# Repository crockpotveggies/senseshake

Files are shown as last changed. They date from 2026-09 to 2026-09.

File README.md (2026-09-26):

Groundlark — lark and seismic waveform

# Groundlark — an open source seismic acquisition platform with support for FPGAs and BISCUT AI chips

Groundlark is an open hardware seismic acquisition platform combining a
Raspberry Pi, a three-IMU DAQHAT-01 sensor HAT, a Trenz Artix-7 200T FPGA module,
and a passive geophone.

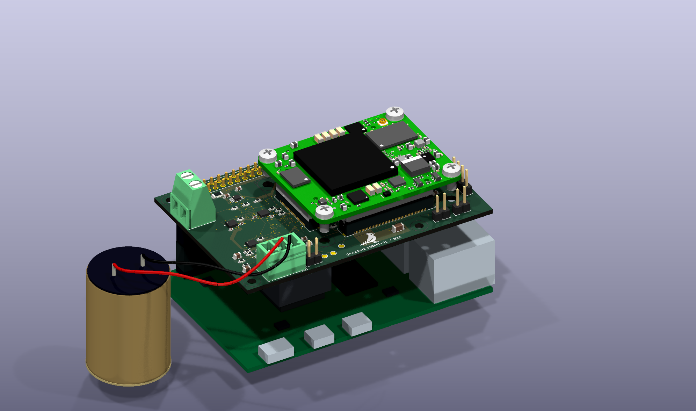
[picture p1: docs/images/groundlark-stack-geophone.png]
Groundlark: Raspberry Pi, DAQHAT-01 and Trenz FPGA stack with Racotech geophone


The image uses current HAT CAD and the vendor Trenz model. The Pi, baseline
socket and geophone are conceptual geometry; lead routing is illustrative.
The J1 procurement substitute needs a physical stack-height check.

## Hardware

The [DAQHAT-01](docs/trenz-hat.md) is an 85 × 56 mm, six-layer FR-4 carrier with
three XYZ LSM6DSO IMUs and one ADS122C04 input for an external Racotech geophone.
The stack is **Pi → HAT → Trenz FPGA**. It requires a separate regulated
3.3 V-class FPGA supply; follow the guide's voltage and power limits.

The [internal FPGA link](docs/fpga-host-link.md) reserves six QSPI wires and
supports UART, reset and switched Pi-driven JTAG without external ribbon cables.
Pi 4 initially uses SPI6; native quad transfers require a different host solution.
An SPI echo bitstream is implemented; accelerated sensor processing remains future work.

The [USB-C sensor head](docs/usb-sensor-head.md) carries an RM3100 magnetometer
and optional DLVR infrasound sensor. It connects to the Pi for power and data;
its MCU firmware is still pending. These sensors are separate from the HAT.
The [A2 ASIC HAT](docs/design-a0.md) and [Coldfoot integration](docs/coldfoot-integration.md)
are retained as a separate design; current hardware work focuses on the FPGA stack.

Use the [stack assembly guide](docs/stack-assembly.md) and
[JLCPCB instructions](docs/jlcpcb-assembly.md) for mechanical and manufacturing details.
The JLCPCB package targets **one assembled HAT**. Upload the corrected BOM and
CPL together. Supplier quantity, sourcing, placement and J1 fit checks remain open.
Fabrication packages stay local under ignored `hw/releases/`.

Physical power, fit, timing, noise and thermal qualification remain pending.
The [bench procedure](docs/bench-procedure.md) describes the required measurements.

## Sensor workbench

The dark-mode Python UI includes a selectable 3D HAT and geophone, six virtual
sensor streams, raw-data charts, stimulus/fault controls and recording/replay.
No hardware or Docker is required. Follow the
[beginner walkthrough](docs/sensor-workbench.md) to create your first signal.

```powershell
# Windows: set up once, then launch
./setup-ui.ps1 -Check
./ui.ps1
```

On Linux/macOS, use `sh ./setup-ui.sh --check`, then `sh ./ui.sh`.
Open **http://127.0.0.1:8080**. Tools and dependencies stay in ignored `.local/`.

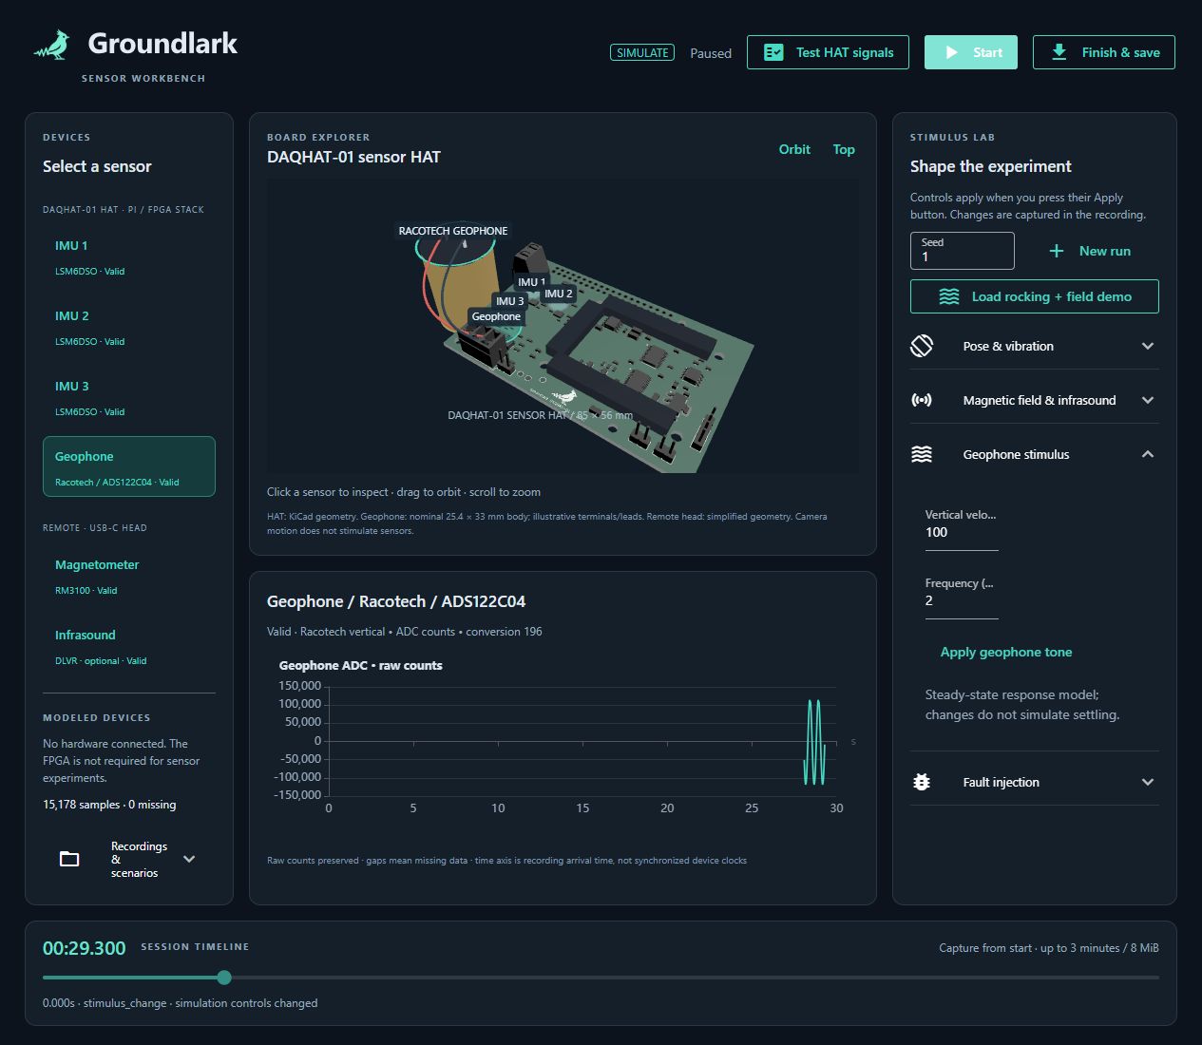
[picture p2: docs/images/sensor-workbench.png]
Groundlark sensor workbench showing the external geophone and a simulated 2 Hz signal


This is an actual browser screenshot with simulated data. Select the geophone
can or its HAT input to highlight both and inspect the same ADC stream.
**Test HAT signals** runs eight simulated seconds through production Pi drivers
on modeled buses, with signal checks and downloadable recordings/results.
The UI simulates and replays; physical acquisition uses the [Pi software](docs/sensor-software.md).

## Project files and tests

| Directory | Contents |
| --- | --- |
| [hw/](hw/README.md) | Atopile circuits, KiCad boards, models, hardware checks and SPICE. |
| [sw/](sw/README.md) | Pi acquisition, contracts, simulator, FPGA and remote firmware interfaces. |
| [docs/](docs/README.md) | Setup, hardware specifications, assembly, interfaces and testing instructions. |
| [environment/](docs/portable-lab.md) | Pinned Docker test environment and bounded cleanup tooling. |

For the full test environment, run `./lab.ps1 build` once, then `./lab.ps1 test`.
Use `./lab.ps1 test -Profile software` for sensor contracts, acquisition,
recording/replay and recovery. See the [portable lab guide](docs/portable-lab.md)
for Linux commands, test scope, five-run retention and cleanup.

Hardware sources: [DAQHAT-01 circuit](hw/elec/hat_trenz.ato),
[KiCad PCB](hw/boards/groundlark-daqhat-01/groundlark-daqhat-01.kicad_pcb),
[A2 HAT](hw/boards/groundlark-hat/groundlark-hat.kicad_pcb), and
[USB head](hw/boards/groundlark-field-head/groundlark-field-head.kicad_pcb).
See [build instructions](docs/build.md) and [source references](docs/sources.md).

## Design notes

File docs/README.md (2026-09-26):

# Documentation

## Getting started

- [Sensor workbench](sensor-workbench.md): installation, first experiment, recordings and replay.
- [Sensor software](sensor-software.md): command-line simulation and Pi acquisition.
- [Stimulus scenarios](stimulus-models.md): saved inputs, waveforms and sensor-model limits.
- [Project layout](project-layout.md): where to find hardware, software and generated files.

## Hardware and assembly

- [DAQHAT-01 hardware](trenz-hat.md): sensors, Trenz module, power, connectors and fabrication stack.
- [Pi/FPGA host link](fpga-host-link.md): SPI/QSPI pins, UART, JTAG and bring-up.
- [Geophone input](geophone-input.md): Racotech connection, analog circuit and accelerometer axes.
- [Stack assembly](stack-assembly.md): Pi, HAT, FPGA, cooling, supports and geophone lead.
- [JLCPCB assembly](jlcpcb-assembly.md): upload files, selected parts, placement and manufacturing requirements.
- [Physical bench procedure](bench-procedure.md): power, fit, timing and noise measurements.
- [A2 ASIC HAT](design-a0.md), [Coldfoot module](coldfoot-integration.md) and [A2 validation limits](validation.md).
- [USB sensor head](usb-sensor-head.md): magnetometer, optional infrasound and firmware interface.

## Interfaces and reproducible builds

- [Sensor data contract](sensor-contract.md) and [schema tools](../sw/interfaces/README.md).
- [GNSS timing](utc-timing.md): legacy hardware/recording support; GNSS is absent from DAQHAT-01.
- [Hardware build](build.md), [portable tests](portable-lab.md) and [SPICE scope](../hw/simulation/README.md).
- [Component and vendor references](sources.md).

The hardware is an engineering prototype. Modeled tests do not replace physical
power, fit, timing, thermal or noise qualification.

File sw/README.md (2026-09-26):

# Software

The sensor HAT is driven by Pi software; it does not need separate MCU firmware.
The [acquisition software](../docs/sensor-software.md) supports sensors on the
DAQHAT-01 FPGA stack and runs without Coldfoot or a configured FPGA.
The sensor contracts and Pi acquisition application are executable:

- [interfaces/](interfaces/README.md): Protobuf schemas, semantic validation and bounded USB framing.
- [pi/](pi/README.md): Pi device configuration, sensor drivers/adapters, acquisition,
  calibration and timestamps. Coldfoot host integration is deferred.
- [field-head/](field-head/README.md): microcontroller firmware for the remote
  USB-C magnetometer/infrasound board.
- [fpga/](fpga/README.md): Trenz pin/connectivity qualification and minimal test
  bitstreams; accelerator implementation is deferred.
- [tests/](tests/README.md): portable replay, fault injection and host integration.
- [ui/](ui/README.md): Python/NiceGUI local sensor workbench, board explorer,
  stimulus controls and recording/replay.

Run `./lab.ps1 test -Profile software` after rebuilding the portable image.
This checks schemas, compatibility, acquisition/replay, modeled bus drivers,
USB streams and recovery from injected faults. See the
[software run guide](../docs/sensor-software.md). USB-head firmware, FPGA test
bitstreams and physical qualification remain pending. Tests do not emulate
Pi/MCU instructions or enumerate a USB sensor head.

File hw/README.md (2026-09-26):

# Hardware

| Board | Native CAD | Circuit source |
| --- | --- | --- |
| A2 Coldfoot ASIC HAT, 120 × 56 mm | [KiCad](boards/groundlark-hat/groundlark-hat.kicad_pcb) | [atopile](elec/hat.ato) |
| DAQHAT-01 Trenz FPGA HAT, 85 × 56 mm | [KiCad](boards/groundlark-daqhat-01/groundlark-daqhat-01.kicad_pcb) | [atopile](elec/hat_trenz.ato) |
| Remote USB magnetometer/infrasound head, 70 × 45 mm | [KiCad](boards/groundlark-field-head/groundlark-field-head.kicad_pcb) | [atopile](elec/field_head.ato) |

`ato.yaml` owns the build targets. `elec/` owns connectivity; `layout*.json` owns
placement metadata. `boards/` contains routed deliverables, BOMs and rendered
previews. `libraries/` and `models/` are shared dependencies with relative CAD
references. Stack concept boards are visualization artifacts, not fabrication
boards.

Use the root portable lab for routine checks. See the [build guide](../docs/build.md),
[Trenz guide](../docs/trenz-hat.md) and [validation limits](../docs/validation.md)
before invoking the lower-level authoring tools.

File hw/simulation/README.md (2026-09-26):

# Hardware simulation scope

The active DAQHAT-01 adds 15 ngspice cases in `geophone/`, run with
`python3 hw/tools/simulate_geophone.py`: Racotech mechanical response, coil
loading, passive input filtering, bias and PGA common-mode headroom at nominal
and tolerance corners. See [the circuit and limits](../../docs/geophone-input.md).
These models omit ADC digital filtering, self-noise, parasitic coupling and
physical mounting. The older A2 GNSS circuit below remains historical.

`simulate_geophone_review.py` adds eight passive startup/pulse/recovery cases in
`geophone-review/`, with asymmetric components and leakage. A 50 mV input exceeds
the ADC range, but this model checks passive recovery only. `prefab_review.py`
adds 256 analytical corners at eleven frequencies, a planning noise budget and
read-only layout/fit measurements. Physical measurements follow the
[bench procedure](../../docs/bench-procedure.md).

The FPGA carrier has fourteen additional bounded checks in `trenz/`, run with
`python3 hw/tools/simulate_trenz.py`. These cover DC input budgets, detection of
excessive supply-lead resistance and lumped UART RC loads. They do not simulate
the Trenz regulators or FPGA logic; see [DAQHAT-01 scope](../../docs/trenz-hat.md).
The updated source envelope is 3.35 V ±0.5% at J83 with a 30 mΩ total hot loop
resistance limit. Four load-step cases add 50/200 nH, 20 mΩ capacitor ESR and
26.4 μF effective capacitance for 0.1↔3 A ramps lasting 100 μs. They do not
qualify sub-microsecond FPGA load edges, startup inrush or source control loops.

Run `python3 hw/tools/simulate.py` with ngspice. It writes all 27 circuit decks,
simulator logs and measured limits to `results.json`, failing on a missing or
out-of-range measurement.

| Cases | Model | Acceptance |
|---|---|---|
| 8 | Sensor rail 3.18/3.42 V; source resistance 0.05/0.2 ohm; 500 nH trace; 22 uF bulk at 40/100% effective capacitance; 1 uF aggregate local bypass; 20–200 mA steps | 3.0–3.6 V |
| 4 | USB 4.75/5.25 V, 25/50 mA; 2 ohm cable plus 1 ohm PTC; ideal LDO with 0.4 V headroom; 0.5 ohm sensor switch, 1–25 mA sensor steps | LDO input ≥4.35 V; sensor rail ≥3.20 V |
| 3 | 4.7 kohm +1% I2C pull-up; 50/100/200 pF; 20 ohm open-drain switch | Rise <1 us, low <0.4 V; 100 kHz bus target |
| 1 | 2 Mbaud UART; 47 ohm series, assumed 25 ohm driver and 100 pF | Rise <50 ns; mid-bit high >2.31 V |
| 2 | USB CC 5.1 kohm ±1% pull-down with a 56 kohm source pull-up at 5 V | CC 0.40–0.43 V |
| 8 | Buck power stage: 4.75/5.25 V; 50/600 mA; 4.7 uH ±20%; 31.2 mohm DCR; 26.4 uF effective output capacitance; 0.1 ohm shunt; 45 mohm core connection | Chip rail 3.0–3.6 V; ripple <100 mV; peak inductor current <2 A |
| 1 | Behavioral 200 ms reset release; actual 10 kohm pull-up; assumed 30 pF | Valid low before release, high afterwards |

These are **behavioral/passive support-circuit models**, not full sensor or
Coldfoot silicon models. The buck uses complementary switches with specified
on-resistances and fixed duty adjusted for input voltage. It does not model the
AP63203 compensation, PFM, protection, startup overshoot or load-step recovery.
The sensor supply assumes a regulated source; it does not simulate TLV1117 loop
stability. Reset timing is nominal, not a supervisor tolerance model. Parasitics
are assumed bounds, not extracted PCB values. UART RC analysis is not IBIS/SI signoff.

The LDO thermal budget assumes 200 mA, 5.25 V input, 3.18 V output, 60 °C ambient
and **100 °C/W assumed board thermal resistance**: 101.4 °C estimated junction.
This is not a measured temperature. Coldfoot has a 600 mA total design envelope,
with at most 500 mA through the two core contacts and 300 mA through any contact.
Its actual current remains to be measured.

Bench work must cover capacitor DC-bias derating, regulator startup/stability,
clock edges at the chip, reset/brownout, maximum-activity rail droop, cable
hot-plug/ESD, magnetic noise with the Pi and accelerator active, GNSS RF layout
and pressure-sensor pneumatics. These checks do not establish fabrication release.

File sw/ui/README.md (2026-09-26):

# Python sensor workbench

From the repository root, run `./setup-ui.ps1 -Check`, then `./ui.ps1`.
On Linux/macOS, use `sh ./setup-ui.sh --check`, then `sh ./ui.sh`.
Open `http://127.0.0.1:8080`; Ctrl+C in the terminal stops the server.
See the [beginner walkthrough](../../docs/sensor-workbench.md).

Rerun `./ui.ps1 -Check` / `sh ./ui.sh --check` for the HTTP and scene tests.
The full acquisition/controller tests use the portable software profile.

- `main.py`: Python page construction, charts, board scene and user callbacks.
- `geophone_scene.py`: selectable external geophone and illustrative leads.
- `test_geophone_scene.py`: geometry and shared ADC/can selection regression.
- `style.css`: visual styling and responsive layout; dark by default.
- `pyproject.toml`, `uv.lock`: isolated, reproducible optional UI environment.
- `check.py`: page-construction/asset-delivery smoke check.
- `assets/`: checked display assets and provenance, separate from editable CAD.
- `build_wordmark.py`: compose the original favicon and outlined UI lettering
  for the shared README/header asset; see `assets/README.md` for regeneration.
- [workbench.py](../pi/groundlark/workbench.py): bounded framework-independent
  simulation/recording/replay controller.
- [test_workbench.py](../tests/test_workbench.py): controller regression tests.
- [hat_signals.py](../pi/groundlark/hat_signals.py): measured HAT signal regression
  behind the **Test HAT signals** button, using production drivers on modeled buses.

The UI is authored in Python. NiceGUI supplies bundled browser components based
on Vue, Quasar, Three.js and ECharts. There is no custom JavaScript application,
Node dependency install, npm build, or separate frontend server in this project.

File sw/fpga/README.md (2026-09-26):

# Trenz FPGA integration

DAQHAT-01 reserves six SPI/QSPI signals and retains UART/reset. Four data-link
wires switch to dedicated JTAG for programming directly from the Pi. See the
[host-link guide](../../docs/fpga-host-link.md) and
[pin contract](../../docs/trenz-gpio-breakout.csv).

The initial Pi 4 transport is ordinary SPI6, with DQ2/DQ3 unused. Quad needs a
separate host engine and reviewed slave RTL. Keep sensor acquisition independent
of FPGA configuration. Coldfoot integration remains deferred; an existing Nexys
Video bitstream is not a Trenz port.

`rtl/daqhat_01_link.sv` is a single-clock 50 MHz SPI echo mailbox with length/CRC/sequence
checks and one-frame backpressure. Run `python3 sw/fpga/test.py` with the pinned
Icarus installation, or use the full/software lab profile. `build.tcl` implements
it for XC7A200T-FBG484-1 in Vivado; run from ignored `.local/` storage. The
[recorded implementation evidence](verification/result.json) includes timing,
CDC, DRC and source hashes. Physical Pi/Trenz programming remains untested.

`cosim.py` connects the production Python client to simulated RTL pins, covering
all 193 payload sizes, sequence wrap, 20 clock phases and 491 malformed/reset cases.
`verify_reports.py` rejects stale source/report hashes, missing timing coverage,
negative slack and reported CDC/DRC findings. After a successful Vivado build,
record it with `python sw/fpga/verify_reports.py --record /path/to/output`, then
run the portable tests. The portable evidence check verifies those recorded
results; it does not run Vivado inside Docker.

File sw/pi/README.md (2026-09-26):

# Raspberry Pi software

Executable acquisition, calibration, bounded recording/replay, Linux adapters
and deterministic simulation are in `groundlark/`. No configured FPGA is needed.
See the [run guide and recovery policy](../../docs/sensor-software.md).
Use the [stimulus guide](../../docs/stimulus-models.md) for motion/field/pressure
waveforms, GNSS trajectories and timed faults. Example: add
`--scenario sw/pi/profiles/stimulus-demo.json` to the simulation command.

Separate pure processing/protocol logic from Linux I2C/SPI/UART/USB adapters so
the same application can run against recorded samples and fault-injecting fakes.
Use the [DAQHAT-01 sensor/carrier design](../../docs/trenz-hat.md) and
[USB interface contract](../../docs/usb-sensor-head.md). Coldfoot integration is
deferred; if resumed, its host semantics remain owned by the current
`docs/runtime_contract.md` in the separate Coldfoot SoC repository.

Run `./lab.ps1 test -Profile software` for the complete portable demo and tests.
Live adapters cover LSM6DSO, SCL3300 and MAX-M10S. Bus logic has modeled-response
tests. [Pi 4 deployment](deploy/README.md), IRQ-assisted FIFO acquisition and PPS
edge recording are implemented. [UTC capture/correlation](../../docs/utc-timing.md)
and [bench report tools](../../docs/bench-procedure.md) are available; physical
timing bounds and validation remain bring-up work. USB ingestion expects a v1 producer;
the STM32 head still needs firmware.

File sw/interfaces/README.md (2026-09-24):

# Sensor interfaces

[Sensor contract v1](../../docs/sensor-contract.md) defines units, time, bounds,
loss and USB framing. Protobuf lives under `proto/`; `buf.yaml` enables STANDARD
lint and FILE compatibility checks. `baseline.binpb` is the frozen initial
descriptor, intentionally tracked as a compatibility fixture. Do not regenerate
it just to make a breaking check pass. Change it only for an explicitly reviewed
new contract version, with migration fixtures.

From the repository root, build the updated portable image once with
`./lab.ps1 build`, then run `./lab.ps1 test -Profile software`.
The full and quick profiles also run these checks. On Linux use
`sh ./lab.sh test --profile software`.

Buf 1.73.0 is SHA-256 pinned in `environment/install_buf.py`; the reference
Python codec uses Protobuf 5.29.6 from the existing locked environment. Tests
need no network or hardware. The descriptor and verification output are built
inside the disposable workspace at `sw/build/`, never added to source control.
The lab retains a small report with its usual five-run retention/cleanup.

`python/` contains the reference validator and incremental framing decoder.
`sensor.options` records candidate Nanopb bounds; it is not generated firmware.
The [Pi application](../pi/README.md) uses these contracts for modeled/Linux
adapters, recording/replay and USB input. Real sensor and firmware qualification
remain separate from software checks.

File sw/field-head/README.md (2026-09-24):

# Remote sensor-head firmware

Planned firmware for the USB-C board's microcontroller: magnetometer acquisition,
optional infrasound input, USB descriptors/transport, and recovery from resets
and disconnects. The authoritative interface is the existing
[USB sensor-head contract](../../docs/usb-sensor-head.md), with messages and
framing in the [sensor data contract](../../docs/sensor-contract.md).
Candidate Nanopb bounds exist; actual C/ARM/USB memory fit still needs validation.

Firmware implementation, enumeration tests and physical USB validation are pending.
This firmware is separate from the Pi software that drives the accelerometer HAT.

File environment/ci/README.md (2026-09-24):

# Optional GitHub Actions workflow

`validate.yml` is an inactive template. It runs structure checks, cleanup tests,
fresh atopile builds, PCB validation and bounded SPICE cases, retaining reports
for seven days. Both referenced GitHub actions are pinned by commit.

The current GitHub OAuth login lacks the `workflow` scope, so GitHub refused an
attempt to install this file under `.github/workflows/`. The project and local
validation do not require changing those permissions.

To enable CI later, use credentials authorized to manage workflows and copy this
file to `.github/workflows/validate.yml`, then commit and push. Local equivalents:

```powershell
python environment/check_project.py
.\lab.ps1 build
.\lab.ps1 unit
.\lab.ps1 test
```

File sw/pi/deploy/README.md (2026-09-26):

# Pi 4 deployment

The supplied overlay targets the current Pi 4 / BCM2711 design. Do not assume
the same GPIO chip or controller configuration on a Pi 5. This is an explicit
bring-up procedure; no workstation boot configuration is changed by the lab.

1. Build `groundlark-daqhat-01.dtbo` with `dtc -@ -I dts -O dtb -o
   groundlark-daqhat-01.dtbo groundlark-daqhat-01-overlay.dts` on the Pi. Install the result
   under `/boot/firmware/overlays/` and add `dtoverlay=groundlark-daqhat-01` to the
   `[pi4]` section of `/boot/firmware/config.txt`. Ensure the following settings
   are not unintentionally restricted by that section.
2. Remove conflicting SPI chip-select overlays. Do not enable `w1-gpio` or
   `pps-gpio` on BCM4: it is now the geophone DRDY signal. Do not
   enable a kernel IMU driver on the same SPI devices.
3. Reboot. Load `spidev` and `i2c-dev` with `sudo modprobe spidev` and
   `sudo modprobe i2c-dev`. Run `python3 bind_spi.py` to verify all five device
   identities, then `sudo python3 bind_spi.py --apply`. The script will not
   detach a different driver. Repeat binding after a reboot.
4. Verify `/dev/spidev0.0` through `.4`, `/dev/i2c-1`, and the GPIO line mapping
   with `gpioinfo`. Grant the acquisition user access using the Pi's spi/i2c/gpio
   groups. Check the example JSON against the actual chip before using it.
5. From the repository, run `python sw/tools/sensor.py live --fifo --profile
   sw/pi/profiles/daqhat-01.example.json --seconds 60 --output sw/build/bench-001.ssrec`.
   Use a new output filename each time. Start with the FPGA supply off.

Chip-select order is BCM8,7,5. IRQ order is BCM27,22,23. Sensor OE is
BCM26; geophone DRDY is BCM4 (currently polled over I2C). IRQs are rising-edge hints, backed by a 20 ms periodic drain
so an event missed while servicing the FIFO does not strand data. The application
requests GPIO inputs without a bias; the board drives them through U42.

DAQHAT-01 uses the ADS122C04 at I2C address 0x40. Remove `pps` from old profiles.
The active profile has no GNSS and rejects `--utc`. Geophone conversion counters
report gaps, but polling timestamps do not establish exact sample times.
Conversion gaps do not reset a healthy ADC; real bus faults still trigger bounded
recovery. Modeled independent-clock tests show that current polling does not
preserve every conversion under load.
Dedicated falling-edge DRDY acquisition is the next software step; do not enable
400 kHz merely to claim lossless capture. That speed also needs electrical testing.
Physical qualification follows the [bench procedure](../../../docs/bench-procedure.md).

Build/merge checks run against a small controller fixture. They establish overlay
structure, not a boot test of Raspberry Pi OS or the connected devices.

References: [Pi overlays](https://www.raspberrypi.com/documentation/computers/configuration.html),
[Linux spidev binding](https://docs.kernel.org/spi/spidev.html),
[GPIO v1 event ABI](https://docs.kernel.org/userspace-api/gpio/gpio-get-lineevent-ioctl.html).

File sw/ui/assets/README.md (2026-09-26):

# Board visualization provenance

The workbench favicon uses a teal lark with a seismic waveform tail on dark
navy. `groundlark-icon.png` is the generated master; `groundlark-favicon.ico`
contains browser sizes from 16 to 256 pixels. See the
[generation prompt and export command](groundlark-icon-prompt.md).

`groundlark-wordmark.svg` combines the existing favicon's master PNG
(unchanged) with the name in Segoe UI Bold, matching the Windows system font
previously used in the workbench header. Text is stored as vector outlines so
the README and UI render identically without downloading or installing a font.
Both use this same self-contained image on a navy background. The PCB artwork
and browser favicon remain unchanged.
Regenerate with `python sw/ui/build_wordmark.py --font C:/Windows/Fonts/segoeuib.ttf`
using build-only `fonttools` (verified with 4.63.0). No font binary is distributed.

`daqhat-01.glb` is a display asset exported with KiCad 9.0.9 from the checked DAQHAT-01 PCB.
It includes the routed board's outline, holes, pads, mask, silkscreen and available
stock component models. It is not a manufacturing deliverable.

KiCad's exporter cannot convert the local VRML bodies. The Python scene adds
simplified envelopes for the Pi socket, Trenz connectors. Selection rings use `hw/layout-trenz.json` XY values.
The remote head is a separate placement-based schematic 3D view; its optional
pressure sensor is shown even though the default assembly is DNP.

The external geophone is authored in Python in `../geophone_scene.py`, with a
25.4 mm diameter / 33 mm high Racotech body. Terminals and leads to J90 are
illustrative. Its selectable can and the ADC both map to sensor 9, and both
highlights follow the same selection. It adds no synthetic data stream or
mechanical motion to the acquisition models. Scene source is also hash-pinned.

Regenerate from the repository root on the Linux lab toolchain:

```sh
kicad-cli pcb export glb --force --no-dnp --include-pads --include-silkscreen \
  --include-soldermask --subst-models --output sw/ui/assets/daqhat-01.glb \
  hw/boards/groundlark-daqhat-01/groundlark-daqhat-01.kicad_pcb
```

The exporter reports missing local VRML models and may return nonzero despite creating
the GLB. Inspect the result and missing-model inventory before accepting it.
Do not ignore other export failures. The scene converts GLB metres/Y-up to
centimetres/Z-up, subtracts the CAD origin (50, 50 mm), then centres the 85 x 56 mm
board. The placement coordinates themselves are unchanged.

`provenance.json` pins the PCB, placements and display asset. Update its SHA-256
values only after re-export and alignment review. Startup fails on stale inputs.
Stock KiCad component geometry retains its upstream attribution/license; see
[KiCad's library licensing](https://www.kicad.org/libraries/license/).

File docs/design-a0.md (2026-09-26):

# Groundlark A2 design

**Atopile engineering prototype, 2026-09-23.** This document replaces the earlier
A0 description in place. Electrical source is in `hw/elec/`; native KiCad boards,
derived review schematics, explicit BOMs and reports are in `hw/boards/`.

The Raspberry Pi acquires, timestamps, calibrates and records samples, then
encodes suitable features/events for the existing Coldfoot host runtime. Direct
sensor acquisition by Coldfoot would require new chip functionality and is not
part of this design. No silicon source was modified.

```mermaid
flowchart LR
    IMU[4 × LSM6DSO IMU] -->|SPI + interrupts through isolation buffers| PI[Raspberry Pi CPU]
    TILT[SCL3300 inclinometer] -->|SPI| PI
    GNSS[MAX-M10S GNSS] -->|I2C + PPS| PI
    MAG[Remote RM3100 XYZ magnetometer] --> BUS[STM32F042 USB sensor controller]
    PRESS[Optional DLVR differential pressure] --> BUS
    BUS -->|USB-C cable to Pi USB port: power and data| PI
    PI -->|TXU0202 + 2 Mbaud host UART| CF[Coldfoot on run-1 1×1 module]
    P5[Pi 5 V] --> LDO[Sensor 3.3 V LDO]
    P5 --> BUCK[Coldfoot 3.3 V buck]
    BUCK --> CF
    CLK[2 × independent 25 MHz oscillators] --> CF
    RESET[Supervisor + Pi reset control] --> CF
```

## Sensors

| Function | Selected part | Interface and limitations |
|---|---|---|
| Motion array | 4 × LSM6DSOTR | XYZ acceleration + XYZ angular rate; shared SPI, separate CS/INT1. Inspired by GeoShake. Averaging benefit depends on measured correlation and timing. |
| Precision leveling | SCL3300-D01-10 | SPI, three-axis inclination/acceleration, CRC and off-frame responses. Inspired by AnyShake; leveling assumes stationary installation. |
| Position/time | MAX-M10S-00B | I2C 0x42 and PPS; passive external GNSS antenna on U.FL. Geographic position/time, not stationary heading. |
| Magnetics | Complete PNI 14190 RM3100 XYZ module | Remote I2C 0x20. Measures magnetic variations associated with geomagnetic/auroral activity, not optical aurora. Preserve signed 24-bit data and calibrate installation offsets. |
| Optional infrasound | DLVR-F50D-E1BS-I-NI3F, DNP | Remote I2C 0x28; proposed ±0.5 inH2O (~125 Pa), 3.3 V option. Ordering suffix requires supplier confirmation. Reference volume, controlled leak and wind filtering determine low-frequency performance. |

No geophone or geophone analog front end is present. The magnetometer and
pressure additions are new integrations, not claims of upstream driver support.
See [component references](sources.md) for the selected parts and vendor documentation.

## Power and support components

TLV1117LV33DCYR derives a separate sensor 3.3 V rail from Pi 5 V. It has 10 uF +
100 nF input and 22 uF + 100 nF output capacitance. Local bypass capacitors are
fitted at the IMUs, inclinometer, GNSS and interface ICs.
The SCL3300 A_EXTC/D_EXTC pins each have their own 100 nF capacitor. GNSS V_BCKP
is left open because no backup source is provided.

SN74LVC8T245 forward/return buffers isolate the Pi SPI/PPS/interrupt domains.
GPIO26 controls active-low output enable, pulled high at boot. Chip selects have
10 kohm pull-ups; unused buffer inputs have defined levels. ISO1640 bridges the
I2C power domains; **grounds are joined**, so the assembly is not galvanically
isolated. Its side-1 low output can reach 0.71 V; verify the selected Pi's input
threshold (design requirement VIL ≥0.8 V). Pi-side I2C uses the Pi's pull-ups;
sensor-side and remote buses have 4.7 kohm pull-ups. Begin at 100 kHz.

The remote head is independently powered from the Pi USB port: a 500 mA-hold
PTC feeds an AP2112K-3.3 LDO with 2.2 uF input and 4.7 uF output capacitance.
An STM32F042K6 reads the sensors over local I2C. TPS22919 switches sensor power
off before enumeration and during USB suspend. Separate 5.1 kohm CC resistors
support either USB-C cable orientation; USBLC6 arrays protect data and CC lines.
See [USB circuit and firmware contract](usb-sensor-head.md). Coldfoot retains
its separate supply, clocks and reset; see [integration](coldfoot-integration.md).

## Pi allocation

| Function | BCM GPIO | Physical header pins |
|---|---|---|
| I2C SDA/SCL | 2 / 3 | 3 / 5 |
| GNSS PPS | 4 | 7 |
| SPI MOSI/MISO/SCLK | 10 / 9 / 11 | 19 / 21 / 23 |
| IMU1/2/3/4 CS | 8 / 7 / 5 / 6 | 24 / 26 / 29 / 31 |
| IMU1/2/3/4 INT1 | 27 / 22 / 23 / 24 | 13 / 15 / 16 / 18 |
| Inclinometer CS | 13 | 33 |
| Sensor buffers enable, active low | 26 | 37 |
| Coldfoot UART TX/RX | 14 / 15 | 8 / 10 |
| Coldfoot reset assertion, active high | 17 | 11 |
| Coldfoot UART enable, active high | 25 | 22 |
| HAT ID SDA/SCL | ID_SD / ID_SC | 27 / 28 |

The 24LC32A ID EEPROM has 3.9 kohm bus pull-ups, local bypass, a 1 kohm write
protect pull-up and a programming shunt. No EEPROM image, overlay, driver or
inference model is delivered. Configure each sensor's SPI mode/rate, disable
the serial console for Coldfoot, and measure PPS and sample timestamp latency.

## Cable and mechanics

Use a USB data cable from the remote head to an existing Pi USB host port.
There is no cable connection to the HAT. Select USB-A-to-C or C-to-C according
to the Pi's host port. Begin with a 1–3 m certified cable and measure magnetic
noise at the installation distance. USB-C describes the connector; the device
uses USB 2.0 full-speed, not USB Power Delivery.

The HAT is 120 × 56 mm. Pi mounting holes remain at (3.5,3.5), (61.5,3.5),
(3.5,52.5), (61.5,52.5) mm. It extends beyond the normal outline; support the
overhang and verify cooler, ports, ribbon cables and enclosure clearance.
The field head is 70 × 45 mm. Use nonferrous mounting hardware near RM3100.
The Pi socket mounts underneath; the run-1 module mounts above on a 3 mm stack.

The HAT uses six copper layers, with In1 and In4 reserved for GND. The field head
uses four, with both inner layers reserved for GND. Exact fabrication stackup,
RF impedance and thermal copper review remain release tasks. The GNSS RF route
is held on the front layer; its provisional width is not a 50-ohm signoff.

Mount the field head away from the Pi, fan, accelerator and power converter.
Its orientation must be calibrated separately: the HAT inclinometer cannot
automatically level-correct a remotely mounted magnetometer. Validate pressure
pneumatics, magnetic noise and motion noise before claiming detection sensitivity.

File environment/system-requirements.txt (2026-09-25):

# Native KiCad/pcbnew routing replay uses the system interpreter.
sexpdata==1.0.2 \
    --hash=sha256:92b67b0361f6766f8f9e44b9519cf3fbcfafa755db85bbf893c3e1cf4ddac109 \
    --hash=sha256:b39c918f055a85c5c35c1d4f7930aabb176bd29016e5ba5692e7e849914b2a1a

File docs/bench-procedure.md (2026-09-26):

# DAQHAT-01 physical bench procedure and report

**DAQHAT-01 revision:** GNSS is removed; one external Racotech vertical geophone
uses an ADS122C04 input. See [current circuit, acquisition and validation](geophone-input.md).
GNSS/PPS/RF details below describe the preceding revision or legacy recordings.
The current DAQHAT-01 physical bench template is version 3, with geophone
response/noise/timing and internal FPGA programming/transport checks. Version 2
reports cannot qualify this revision; create a new report and retain old evidence
with its original hardware revision.

This procedure qualifies the assembled Pi/DAQHAT-01/Trenz stack. It is separate from
preparing a prototype fabrication submission. Physical tests run when an assembly
exists; missing physical evidence is recorded as incomplete, not fabricated by a
simulation. The user owns fabrication approval.

## Prepare the report and instruments

Create one report folder under ignored `sw/build/` or dedicated lab storage.
Keep authored procedures here and raw captures outside Git. Retain the completed
report and its attachments with the hardware revision when the bench run ends.

```sh
mkdir -p sw/build/bench-001
python sw/tools/bench.py init sw/build/bench-001/report.json
python sw/tools/bench.py check sw/build/bench-001/report.json
```

The initial check intentionally returns **incomplete**, exit code 2. Record the
operator, UTC date, board serial/revision, software commit, Pi/kernel, geophone serial and calibration,
FPGA bitstream or explicit unconfigured state, instruments/calibration references,
mounting, cooling, temperature range, sample/filter settings and power cases.
Enter application targets for geophone timing error and input noise, inter-IMU skew, acceleration noise,
thermal bias change and FPGA noise ratio before evaluating those tests.

Use a current-limited adjustable supply, DMM, oscilloscope with suitable differential
voltage/current measurements, electronic load, logic analyzer, temperature probes,
calipers and a low-noise differential signal source. Timing qualification needs a
shared instrument timebase of known accuracy. Motion tests also need known
orientations and a reference accelerometer/shaker for frequency/phase characterization.

Store scope exports, logic traces, `.ssrec` recordings, analyzer JSON and fit photos
inside the report folder. Generate each evidence entry with:

```sh
python sw/tools/bench.py evidence sw/build/bench-001/report.json sw/build/bench-001/trace.csv
```

Copy the returned relative path/hash into the relevant check's `evidence` list.
Every measured check needs evidence. The checker rejects missing/altered attachments,
outside-folder paths and wrong units. Files are capped at 64 MiB each. It checks
supplied measurements and evidence integrity; it cannot certify instrument setup
or infer physical truth from a filename.

## 1. Power and partial-power operation

1. Inspect assembly/polarity/shorts unpowered. Begin with Trenz unconfigured and
   external power current limited. J83 pin 1 is positive, pin 2 ground. Use the
   documented 3.35 V ±0.5% source; the Pi sensor supply remains separate.
2. Capture cold startup at J83, the module management rail and the sequenced I/O
   rail, plus input current and reset/enable/PGOOD where accessible. Evaluate
   ramp/sequence/reset behavior against the installed Trenz revision and regulator
   documentation. The ordinary operating minimum is not a requirement at t=0.
3. Once operating, measure minimum/maximum module management voltage during idle,
   intended FPGA load, Pi stress and 0.1↔3 A characterized load steps. Record
   actual edge rates and ringing. The simulation's 100 µs ramp is not a substitute
   for faster measured switching behavior. Avoid double-counting FPGA plus dummy
   load: the total initial operating envelope is 3 A.
4. After thermal settling, measure the complete positive-and-ground loop drop
   differentially at a known current: R = ΔV/I. Include connectors, fuse, copper
   and return paths. Record probe locations and uncertainty.
5. Repeat Pi-only, FPGA-only, both-powered and both turn-on/off orders. Capture
   leakage/back-power, reset/OE levels and interface behavior against component
   limits. Summarize `power_sequence` and `partial_power_isolation` only after all
   cases are covered, with individual traces in the evidence.

Fixed report limits: operating module rail **3.201–3.399 V** and hot loop
**≤0.030 Ω**. If limits fail, correct supply/path/decoupling/protection and repeat
affected cases. Document measured inrush and component temperatures in the notes;
they are evaluated against the actual component ratings, not invented thresholds.

## 2. Mechanical fit

Assemble the intended Pi, SSQ riser, DAQHAT-01, Trenz, cooler and four straight supports.
Check full socket engagement and pin orientation, spacer seating without board
bow, fastener clearance, geophone/power-plug withdrawal and cooling access. The
internal FPGA link needs no ribbon cables or external JTAG connector. Measure
closest gaps and record photos. The nominal Pi-to-HAT gap is 27.179 mm; fit depends
on actual socket seating/cooler/cables. A dimensioned mock-up can precede assembly.
Set `connector_cable_cooler_fit=true` only after the intended configuration fits.

## 2a. Internal FPGA programming and transport

1. Follow the [host-link bring-up](fpga-host-link.md#bring-up) on the selected Pi 4
   and kernel. Record JTAG IDCODE, actual TCK frequency and successful volatile
   programming of the recorded bitstream. Set `fpga_jtag_programming=true` only
   after the real scan/load passes; a simulated mailbox is insufficient.
2. Capture BCM25 arm, switch select/request/OE, SCLK/CS and JTAG at both sides
   during SPI-to-JTAG-to-SPI transitions, startup, normal termination and recovery
   from a control-bus failure. Confirm isolation before ownership/direction
   changes. Check Pi-only and FPGA-only power in section 1, including rail ramps.
   Record `fpga_mode_handoff` separately from `partial_power_isolation`. SIGKILL
   and loss of the host have no hardware watchdog; exercise the documented
   disarm/reboot recovery before manually changing ownership.
3. Measure the signals **at the FPGA-side pins**, including the switch and series
   resistors. Enter maximum SPI clock (initially 1 kHz–1 MHz), minimum SCLK high
   and low (each at least 500 ns), and minimum CS setup/hold/inactive (each at
   least 1000 ns). Include instrument uncertainty. The checker enforces these
   conservative bring-up limits; Linux overlay settings alone are not evidence.
   Inspect overshoot, ringing, logic levels and MISO output release against the
   actual devices' limits; retain scope traces and interpretation with the report.
4. Run a recorded loopback soak covering payload lengths 0–192, sequence wrap,
   repeated mode handoffs and concurrent sensor/CPU/storage load. Record duration,
   transaction count, payload seeds, voltage/temperature and all errors. Require
   `fpga_loopback_errors=0` for this valid-traffic soak; report deliberately injected
   faults and recovery separately. A numerical zero without captures and test
   conditions does not establish a bit-error-rate guarantee.

## 3. Geophone, IRQ and acquisition timing

1. Follow [Pi deployment](../sw/pi/deploy/README.md) and capture with `--fifo`.
   The DAQHAT-01 has no GNSS and rejects `--utc`. Read back ADC configuration;
   retain raw counts, conversion counters and host monotonic timestamps.
2. Capture ADC DRDY, I²C transactions, IMU IRQ and SPI activity on a common
   logic-analyzer timebase. Measure conversion-to-read delay, delivered rate,
   latency variation, inter-IMU skew and drift under CPU/storage/network load,
   with the FPGA off, idle and active. The current ADC driver polls; it does
   not turn DRDY into a hardware timestamp.
3. Stop/resume acquisition deliberately. Confirm IMU FIFO behavior and that
   ADC overwrites, integrity faults and ambiguous counter wraps produce faults
   with unknown physical loss. The ADC has no FIFO. Confirm recovery without
   relabeling invalid or saturated samples as valid.
4. Apply calibrated differential inputs within the ADC common-mode and input
   limits, including a 10 Hz sine and a frequency sweep. Measure polarity,
   gain, clipping and recovery. Independently move the vertical geophone with
   a known reference to establish its mechanical response and polarity. An
   electrical signal-generator test alone does not calibrate the geophone.
5. Populate `geophone_polarity_response`, measured maximum geophone timing
   error, inter-IMU skew and recovery checks with the retained traces. Choose
   timing limits from the research use case before evaluating acceptance.

Start with 10 minutes per load state and repeated cold starts, then extend
through thermal settling and the intended operating envelope. No absolute UTC
qualification is implied by this board or a passing relative timing test.

## 4. Noise, thermal drift and FPGA coupling

Record identical sensor settings and rigid mounting with FPGA off, idle and active;
repeat with cooling off/on where thermally permissible. Keep external vibrations
and temperature traces as controlled as practical. Retain thermal settling and
stable intervals separately. Record known orientations and a reference vibration
input for axis, gain and phase checks; package axes are not automatically board axes.

```sh
python sw/tools/measure_hat.py sw/build/bench-001/off.ssrec --output sw/build/bench-001/off.json
python sw/tools/measure_hat.py sw/build/bench-001/active.ssrec \
  --baseline sw/build/bench-001/off.ssrec --output sw/build/bench-001/comparison.json
```

The existing analyzer reports nominal-SI mean, standard deviation, trend, gravity,
sample periods and gaps. It does not yet calculate spectral density or Allan
deviation. For band-limited acceptance, use a documented filter/spectral analysis
and retain its script/settings/output as evidence. Enter worst-axis RMS over the
declared common band, worst thermal bias change and worst active/off noise ratio.
Do not compare runs with different sample/filter settings or use motion-contaminated
standard deviation as a stationary noise floor. Reference calibration and absolute
accuracy remain distinct from repeatability/noise.

## Evaluate and prepare the prototype release

```sh
python sw/tools/bench.py check sw/build/bench-001/report.json
```

Exit 0 means every supplied measurement/evidence item and application limit passes;
exit 2 means incomplete or failed checks; exit 1 means malformed input. Missing
measurements, targets, context or evidence never become a pass. Correct failed
items and repeat the affected tests with traceable revisions.

For the next **prototype fab submission**, freeze the intended DAQHAT-01 revision and
actual stack/copper/dielectric values; follow the current
[assembly requirements](jlcpcb-assembly.md) and [stack instructions](stack-assembly.md);
run the full CAD/build checks; review footprint pin numbering, BOM availability,
DNPs, drill/microvia instructions and mechanical fit; then export and independently
inspect Gerbers/drills, assembly drawings and placements from that same revision.
Retain hashes and a release manifest. Keep the physical bench report pending until
boards arrive, rather than requiring completed-board measurements before making
the first prototype.

For geophone noise, record both a shorted differential input and the connected,
stationary sensor. Convert counts to input volts using the recorded gain and
reference. Measure the defined bandwidth with FPGA off/idle/active and record
`max_geophone_input_noise_rms` against the application target. Separate ambient
ground motion from electronic noise; do not use the synthetic stimulus as evidence.

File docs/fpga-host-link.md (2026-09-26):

# DAQHAT-01: internal Pi / Trenz transport

The 85 × 56 mm HAT now connects the Pi directly to the TE0712-03-81I36-A.
Six wires reserve SPI/QSPI, UART is retained, and a switch shares four wires
with dedicated FPGA JTAG. J84–J89, their expansion fanout, all four ribbons,
the guide and the offset spacer are removed from the active assembly.
The Pi stays below the HAT; the FPGA stays above it for cooling access.

## Wiring and power

| Function | Pi physical pin / BCM | Carrier / module contact | FPGA ball |
| --- | --- | --- | --- |
| SCLK / JTAG TCK | 40 / 21 | J81.21 / JM2.22 | W19 |
| CS_N | 12 / 18 | J81.23 / JM2.24 | W20 |
| DQ0 / MOSI / JTAG TDI | 38 / 20 | J81.22 / JM2.21 | V18 |
| DQ1 / MISO / JTAG TDO | 35 / 19 | J81.24 / JM2.23 | V19 |
| DQ2 / JTAG TMS | 36 / 16 | J81.26 / JM2.25 | Y18 |
| DQ3 | 32 / 12 | J81.28 / JM2.27 | Y19 |
| Pi TX / FPGA UART RX | 8 / 14 | J81.12 / JM2.11 | AA21 |
| Pi RX / FPGA UART TX | 10 / 15 | J81.14 / JM2.13 | AA20 |
| Application reset control | 11 / 17 | J81.13 / JM2.14, through existing transistor | AB22 |

In programming mode the switch selects dedicated JTAG contacts J81.94/96/98/100,
not the application balls in the table. R80 keeps the module CPLD's JTAGEN low.
The complete [contact map](trenz-pin-map.json) includes 149 unused ordinary I/Os;
the audit checks all 260 module contacts against independent vendor fixtures.
Sensors retain SPI0, I2C1 and their existing interrupts. Ethernet is not exposed.

U100/U101 are TMUX1574 bidirectional switches. U102 is a TCA9534 at I2C1 address
0x20: P0 selects JTAG; P1 requests enable. U103/U106 permit a connection only
with the request, BCM25 arm and both rail-good signals asserted. BCM25 also
retains its existing UART-enable role. The link tool owns BCM25 while running;
do not run a separate UART-enable controller concurrently.

U104/U105 monitor Pi/FPGA 3.3 V with TLV809EA30DBZR supervisors (3.0 V threshold,
nominal 200 ms release). Each new IC has local 100 nF decoupling. R100–R105 are
22 Ω series footprints; pulls define reset/idle states. The switch's unselected
CS/DQ3 parking contacts are open, so they cannot short Pi outputs to ground.
TMUX1574 provides powered-off signal isolation at VDD=0 and fail-safe controls.
Settled-state simulation does not characterize subthreshold power ramps.

J83 still requires the [regulated external supply and operating envelope](trenz-hat.md#power-and-interfaces).
The [assembly guide](stack-assembly.md) specifies the existing GPIO riser and
four straight supports. Use the recorded six-layer stock stack and fill/cap all through-vias,
including the ADC supply vias and the through-via at U101.4.

## Initial transport and bitstream

Pi 4 uses **SPI6, mode 0, CE0 only, initially ≤1 MHz**. DQ2/DQ3 are reserved;
its Linux SPI controller does not perform native quad transfers. The reference
bitstream advertises no quad capability. JTAG runs at a requested 100 kHz;
measure the actual clock before changing the native GPIO adapter calibration.

The [reference RTL](../sw/fpga/rtl/daqhat_01_link.sv) is an echo/mailbox bring-up design.
It uses the module's default 50 MHz CLK50M2 at R4; the exact revision-03 schematic
shows its 1.5 V level translation and bank supply, so its XDC uses LVCMOS15.
Application bank 14 uses LVCMOS33. The bitstream does not configure DDR, Ethernet,
Coldfoot or the Si5338. Verify the clock generator still has its factory settings.

At this conservative rate, SPI is oversampled in one 50 MHz domain through
three-stage synchronizers. A one-frame mailbox replaces the proposed asynchronous
FIFO: there is no second fabric clock domain to cross. CS setup/hold and the
interval between transactions must each be at least 1 µs; SCLK high/low at least
500 ns. The overlay requests 1 µs CS setup/hold/inactive delays through the Linux SPI
core; use a kernel supporting those properties (reviewed against Pi Linux 6.12).
The Pi tool checks the overlay and inserts a 1 ms transaction gap. MISO is undriven immediately
when CS is high. UART has electrical loopback for separate diagnostic testing.
Unused quad ports are optimized out; the bitstream leaves unused pins undriven.

Vivado 2025.2 built the XC7A200T-FBG484-1 bitstream. Recorded timing is +10.143 ns
setup / +0.109 ns hold slack at 50 MHz, zero internal unconstrained endpoints;
see [reports and source hashes](../sw/fpga/verification/result.json). Asynchronous
input exceptions and bounded output propagation are explicit in the XDC.
These reports do not qualify the Pi controller, switch or board timing.

## Wire contract

Every command is one CS-delimited transaction, MSB-first within each byte.
The first received byte is a dummy. Multi-byte integer fields are little-endian.

| Command | Bytes after command | Behavior |
| --- | --- | --- |
| 0, status | Clock 8 zero bytes | `SSFP`, version 1, capabilities 0, flags, error |
| 1, submit | Exact encoded frame | Commit only at CS release after length and CRC validation |
| 2, read | Clock 206 zero bytes | Result frame padded with zeroes; repeated reads do not consume it |
| 3, acknowledge | uint16 sequence | Free only the result with this sequence |

Flags: 0 busy, 1 empty, 2 result available. Frame: `SSFP`, version byte 1,
operation byte 1 (echo), uint16 sequence, uint16 payload length, 0–192 payload
bytes, CRC-32/IEEE over header and payload, stored little-endian. Maximum 206 bytes.
Status errors are sticky until application reset/reconfiguration: 1 overflow,
2 invalid frame, 3 CRC, 4 incomplete transaction, 5 busy write, 6 wrong ACK,
7 unknown command. Busy writes preserve the existing result. Invalid results
are never acknowledged by the Python client. A timed-out write has unknown
outcome; the client does not automatically repeat it.
The processing timeout is checked before and after each status transaction;
late ready responses are not consumed. ACK completion requires a subsequent empty
status. An interrupted reset discards the current transaction through CS release;
MISO is undriven during reset, and the next complete transaction starts cleanly.

## Bring-up

Install the sensor overlay first. Compile the optional
[`groundlark-fpga-overlay.dts`](../sw/pi/deploy/groundlark-fpga-overlay.dts)
with `dtc -@ -I dts -O dtb`, install it in the Pi's overlays directory and add
`dtoverlay=groundlark-fpga` to the active boot configuration. Enable I2C1.
Do not combine with other SPI1/SPI6 or GPIO18–21/12/16 consumers. CE1 remains
disabled because BCM27 belongs to IMU1. Ensure the `spidev` module is loaded.

The following commands run **on the Pi**, from the repository, after verifying
which gpiochip represents BCM2711. OpenOCD 0.12.0 with bcm2835gpio is required.

```sh
sudo python3 sw/tools/fpga.py scan --gpiochip /dev/gpiochip0
sudo python3 sw/tools/fpga.py program --gpiochip /dev/gpiochip0 --bitstream /path/to/daqhat-01-link.bit
sudo python3 sw/tools/fpga.py status --gpiochip /dev/gpiochip0
sudo python3 sw/tools/fpga.py loopback --gpiochip /dev/gpiochip0
```

The tool locks the link, disarms it, initializes the expander's output latch
before directions, and verifies register readback. For JTAG it unbinds SPI6's
controller, claims safe GPIO directions, then enables the switch. It isolates
before restoring SPI6. GPIO25 provides disarm even if I2C fails; I2C disable
is attempted even if the GPIO operation fails. A control-bus failure keeps
ownership faulted; restore power/control and reinitialize before reuse. Driver
restoration failure also latches this fault. SIGTERM and Ctrl-C unwind the
isolation path. Termination that bypasses cleanup (including SIGKILL) has no hardware watchdog: GPIO output
state may remain latched. Restart through this tool (which first drives BCM25
low), or power-cycle/reboot before manual driver changes. Reboot restores a
controller left unbound. Sensor acquisition remains independent.
Programming loads volatile FPGA configuration only; it does not write flash.

Build the bitstream from an ignored output directory using Vivado:

```text
vivado -mode batch -source /absolute/path/to/groundlark/sw/fpga/build.tcl
```

## Verification and remaining measurements

The portable lab includes RTL packet/fault simulation, production Python-to-RTL
co-simulation, host framing/ownership tests, 38 behavioral-switch/RC checks,
native CAD checks and sensor regressions. Full and quick profiles now run
`hw/tools/replay_trenz.py`, rebuilding the complete native routing in a
temporary directory and comparing every copper object. A separate parts fixture
checks all 32 link components against authored metadata, BOM and PCB fields.
Current rendered and
interactive models use the revised board; the Pi model remains conceptual.

Still measure first-article rail ramps/current, actual stack seating, SPI/JTAG
edges and switching, and sensor noise with the FPGA idle and active. Linux driver
handoff and JTAG programming have not been exercised on a physical Pi/Trenz stack.
Quad throughput and accelerated processing remain future work.
See [assembly requirements](jlcpcb-assembly.md) and the
[bench procedure](bench-procedure.md) for production preparation and physical qualification.

Sources: [exact module schematic](vendor/trenz/SCH-TE0712-03-81I36-A.PDF),
[TMUX1574](https://www.ti.com/lit/ds/symlink/tmux1574.pdf),
[TCA9534](https://www.ti.com/lit/ds/symlink/tca9534.pdf),
[SN74LVC1G10](https://www.ti.com/lit/ds/symlink/sn74lvc1g10.pdf),
[SN74LVC1G08](https://www.ti.com/lit/ds/symlink/sn74lvc1g08.pdf),
[TLV809E family](https://www.ti.com/lit/ds/symlink/tlv803e.pdf).

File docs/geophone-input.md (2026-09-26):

# DAQHAT-01: one Racotech geophone

The active 85 × 56 mm DAQHAT-01 carrier replaces MAX-M10S U21, U.FL J2 and the
GNSS support capacitors with one external passive vertical geophone input.
Historical A2 and the remote USB magnetometer/infrasound board are unchanged.
All 155 Trenz GPIO assignments remain required and independently checked.

## Sensor and connector

Specify **Racotech RGI-4.5Hz, vertical, 395 Ω ±5%, 23.4 V/(m/s) ±10%,
4.5 Hz ±0.5 Hz, damping 0.70 ±10%**. Raspberry Shake documentation also calls
this its 4.5 Hz RGI-20DX; do not order another RGI-20DX frequency by name alone.
The bare element is 25.4 mm diameter × 33 mm high. Its ground-coupled external
mount must hold it vertically; HAT leveling does not establish the leveling of
a separately mounted geophone.

J90 is Phoenix Contact **1803439**, MCV 1,5/3-G-3,81. Use a matching
MC 1,5/3-ST-3,81 cable plug. Pin 1 is GEO+, pin 2 GEO−, pin 3 cable shield/GND.
The two coil wires float relative to ground and require no external power.
Use a shielded twisted pair; terminate its shield at J90, not a coil terminal.
This connector is incompatible in purpose with J83's external FPGA supply.
The render shows the PCB header, not the cable plug or external geophone.

## Circuit

- U22: ADS122C04IPWR, 24-bit delta-sigma ADC with internal PGA and 2.048 V
  reference, AIN0−AIN1, I²C address 0x40. Initial software: gain 64, normal
  330 SPS. The 24-bit word is not a claim of 24 noise-free bits.
- D90: TPD2E2U06DCKR at the connector; R90/R91 are 1 kΩ series input resistors.
  Protection is intended for handling ESD, not outdoor lightning or arbitrary
  sustained applied voltage. Qualification of the protection remains physical.
- C90: 100 nF C0G across the differential input. Baseline CAD names TDK
  C3216C0G1H104J160AA; the reviewed assembly selection is Murata GRM31C5C1H104JA01L
  (C97946), retaining 50 V, +/-5% and 1206; see [assembly selections](jlcpcb-assembly.md);
  C91/C92: 1 nF C0G to ground.
  C0G avoids using piezoelectric high-k ceramics on the measurement input.
- R92/R93: 1 MΩ bias returns to filtered mid-supply. R94/R95: 10 kΩ divider;
  C93: 10 µF. This loads the coil lightly; no additional damping shunt is fitted.
- R96: 22 Ω analog supply filter; C94/C95: 10 µF + 100 nF at AVDD;
  C96: 100 nF at DVDD. RESET is tied high. Unused analog/reference pins float,
  following TI's unused-input guidance; excitation and burnout currents are off.
- R97: 10 kΩ DRDY pullup. U42 carries its active-low output to Pi BCM4,
  formerly PPS. Existing I²C isolation and pullups are retained.

Nominal input full scale is ±32 mV. Well above the mechanical corner this is
approximately ±1.37 mm/s before loading and filtering; it is not a flat
velocity range below 4.5 Hz. The nominal electrical pole including the coil
is approximately 662 Hz. The ADC's own digital filter also shapes the response.
TI specifies typical 0.50 µV RMS ADC input noise at gain 64 / 330 SPS / 3.3 V;
this excludes the sensor, resistors, cable and board interference.

No analog hyper-damper or inverse-response compensation is implemented. Do not
claim Raspberry Shake's or AnyShake's sub-hertz system response for this board.
Preserve raw counts and characterize the assembled response before correction.

## Accelerometer axes

U11–U13 are three **three-axis** LSM6DSO IMUs, all on the front at rotation 0°.
Each measures X, Y and Z; rotating the chips is unnecessary to obtain three
axes. Three sensors provide three independent readings per axis. Raw values
retain the ST package-axis convention. No geographic orientation or automatic
averaging is implied. Hardware tests reject a rotated/flipped placement until
an explicit software axis mapping is provided. The external geophone adds a
single vertical velocity-sensitive channel.

## Acquisition and validation

Sensor ID **9** carries signed 24-bit ADC counts and the 8-bit conversion
counter. ID 6 remains reserved for legacy GNSS recordings. The active inventory
is 1–3 and 9 (IDs 4/5/6 are reserved for legacy recordings); remote IDs remain 7 and 8. Configuration carries gain and reference.
Nominal input volts = counts × 2.048 / (64 × 2²³); velocity requires the sensor
transfer function and calibration, not simple division across all frequencies.

The Pi driver resets and reads back all registers, enables inverted-data
integrity and the conversion counter, detects duplicates/gaps/wrap ambiguity,
and marks signed endpoints saturated. There is no ADC FIFO. The current driver
polls; BCM4 is routed for future falling-edge timestamp acquisition. Poll
completion timestamps have unknown absolute uncertainty, and overwritten
conversion loss is unknown. Scheduler/IPC throughput must be measured on the
target Pi; 330 SPS conversion rate does not guarantee 330 delivered samples/s.
ADC data validity does not prove coil continuity; automatic open-coil detection
is not implemented. The current DAQHAT-01 rejects `--utc`; it contains neither GNSS nor a UTC/PPS source.

Duplicate reads do not extend the counter ambiguity window. Conversion gaps emit
missing records with unknown loss, without resetting an otherwise healthy ADC.
Actual communication faults retain bounded hardware recovery. The nominal
330-SPS setting has a 3.04296875 ms conversion period at nominal clock; do not
interpret the configured nominal period as a calibrated device timestamp.
The [bench procedure](bench-procedure.md) covers physical response, noise,
timing and fit. Modeled layout and transient checks do not replace these measurements.

Tests include independent pin maps, three-IMU orientation, ADC wire faults,
counter rollover, signed precision, saturation, contract clock/ID validation,
and a known 10 Hz / 100 µm/s waveform through the actual driver on a modeled bus.
SPICE checks cover 15 frequency/tolerance cases plus bias and PGA headroom.
The stimulus is a steady-state mechanical + passive RC model: no ADC digital
filter, settling, self-noise, magnetic pickup or physical mounting simulation.

Bench qualification must measure polarity/response, shorted-input and attached
sensor noise with FPGA off/on, clipping/recovery, delivery timing/loss, supply
sequence and physical cable/stack fit. Blank physical evidence never passes.

## Primary references

- [Racotech sensor datasheet](https://raspberryshake.org/wp-content/uploads/2020/05/racotech-geophone-datasheet.pdf).
- [TI ADS122C04 datasheet, SBAS751B](https://www.ti.com/lit/ds/symlink/ads122c04.pdf): PW pin map, PGA common-mode, noise table 1, registers and input filtering.
- [TI TPD2E2U06 datasheet](https://www.ti.com/lit/ds/symlink/tpd2e2u06.pdf): DCK pin map and ESD characteristics.
- [Phoenix Contact 1803439](https://www.phoenixcontact.com/en-us/products/pcb-header-mcv-15-3-g-381-1803439).

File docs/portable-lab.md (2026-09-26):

# Portable test environment

**DAQHAT-01 revision:** GNSS is removed; one external Racotech vertical geophone
uses an ADS122C04 input. See [current circuit, acquisition and validation](geophone-input.md).
GNSS/PPS/RF details below describe the preceding revision or legacy recordings.
The current physical bench template is version 3, with geophone and internal
FPGA programming/transport measurements. See the [bench procedure](bench-procedure.md).

The project now has one disposable Docker test environment. Keep authored files
in their existing locations and use the root `lab.ps1` or `lab.sh` launcher for
validation. Existing local virtual environments and historical reports are not
required by this runner and are not removed by cleanup.

## Start here

Prerequisites: Docker with Linux containers, Python 3.12 or newer, and enough
Docker memory for an 8 GiB container. Both are already available on the current
Windows machine. The toolchain is Linux/amd64; other host architectures require
Docker's amd64 emulation and have not been verified.

From the project folder in PowerShell:

```powershell
.\lab.ps1 build                 # Once; needs Internet
.\lab.ps1 doctor                # Show exact installed tool versions
.\lab.ps1 test                  # Full circuit + PCB + SPICE validation
.\lab.ps1 test -Profile quick   # Saved compiled circuit/PCB + SPICE checks
.\lab.ps1 test -Profile spice   # Only bounded SPICE cases
.\lab.ps1 test -Profile software # Sensor application, contracts and recovery
.\lab.ps1 unit                  # Cleanup/staging safeguards
```

On Linux/macOS, use `sh ./lab.sh build`, `sh ./lab.sh test`, and
`sh ./lab.sh test --profile quick`. Alternatively, run
`python environment/host.py test` on Windows or `python3 environment/host.py test`
elsewhere. Paths are relative to the launcher, not the current working directory.
No global Python packages or project virtual environments are installed.

Windows Docker Desktop could not bind-mount this machine's `P:` drive. The
launcher therefore sends an allowlisted source snapshot through Docker's API,
runs against that copy, and copies reports back. This also works without Docker
drive-sharing configuration. No host directory is mounted into the container.

## What each profile proves

| Profile | Checks |
| --- | --- |
| `full` (default) | Fresh atopile builds for A2, USB field head, and DAQHAT-01; numeric constraint solves; unsafe 5 V IMU rejection; independent hardware regressions; native KiCad ERC/DRC/connectivity; DAQHAT-01 power/clearance and pre-fab review; clean routing replay; SPICE; the software profile (22 stages). |
| `quick` | Same GPIO/component fault, circuit/PCB consistency, routing replay, SPICE and software checks using saved compiled layouts. Does **not** prove `.ato` changes were rebuilt. |
| `spice` | 27 A2/field, 14 Trenz, 15 geophone response, 8 geophone transient and 38 host-link switch/RC cases, including expected fault detection. |
| `software` | RTL and Python-to-RTL co-simulation; recorded Vivado evidence/hash gate; Buf format/lint/build and compatibility; acquisition/replay, modeled driver and Linux TTY/worker fault tests; retained eight-sensor demo. No physical hardware execution. |

The runner calls the existing project entrypoints. Routing reconstruction stays
in a temporary tree; it does not rewrite source CAD, render images, or release fabrication files. A full test
compares freshly compiled connectivity with the saved routed boards and should
fail if they disagree.

These are bounded electrical models, RTL simulations and CAD checks. They do not
emulate sensor silicon, USB enumeration, a booted Raspberry Pi or Coldfoot execution.
They do not establish regulator stability, extracted signal/power integrity,
thermal performance, physical mating, or fabrication readiness.

## Where files go

```text
groundlark/
  hw/                circuits, routed CAD, models and hardware checks
  sw/                Pi software, USB firmware and FPGA integration scopes
  docs/              shared design and interface documentation
  environment/       small runner, Dockerfile, dependency lock and safety tests
  lab.ps1 / lab.sh   entrypoints
  .local/            ignored local tools and preserved legacy caches
  .lab/
    .groundlark-lab   ownership marker
    .lock            prevents simultaneous run/cleanup
    runs/<run-id>/   status, input hashes, tool versions, logs, result files
```

The source snapshot, build tree, package caches and tool temporary files live
inside memory-backed container filesystems and disappear when the container
exits. The test process runs without root privileges. Input files are owned by
root and read-only to that process; the container root filesystem is read-only.
There are no persistent Docker volumes, hardware passthroughs, host-network
access, or mounted Docker sockets.

Containment limits:

- Keep the **five newest runs**, including failures. Before a new run, older
  marked runs are removed automatically. Save evidence you need to keep outside
  `.lab` before the next run; do not treat `.lab` as an archive.
- Scratch workspace: 2 GiB; tool temporary files: 512 MiB; source snapshot:
  512 MiB; reports inside a run: 256 MiB. Individual logs/files: 32 MiB.
- Refuse to start if retained host data exceeds 1 GiB after retention cleanup.
  This is a start check, not a host filesystem quota.
- Container: 8 GiB RAM, four CPUs, 256 processes. Each test step times out after
  ten minutes. A container abandoned by a terminated launcher expires after one
  hour. Normal success/failure stops and removes it immediately.
- Test runs use no network. Dependencies are downloaded only during image build.

Each report identifies the exact image ID and tool versions, hashes the inputs,
records step outcomes, and includes generated SPICE decks and logs. The launcher
checks that the host inputs did not change during the run. Reports are copied
back after execution; forcibly terminating Docker can lose that run's in-memory
details. Its host status marker remains for diagnosis and later cleanup.

## Cleanup

```powershell
.\lab.ps1 clean                 # Preview old runs beyond the newest five
.\lab.ps1 clean -Apply          # Remove those old runs
.\lab.ps1 clean -All            # Preview removing every run
.\lab.ps1 clean -All -Apply     # Remove all disposable test evidence
```

Equivalent shell flags are `clean --apply` and `clean --all --apply`. Cleanup
works without Docker. It requires the lab ownership marker, validates every run
marker and final absolute path, refuses symlinks/junctions and unknown folders,
and acquires the same lock used by tests. It only removes recognized run folders.
It leaves authored files, CAD, existing virtual environments, and the old `C:`
project copy alone. An unexpected folder causes cleanup to stop for inspection.

The reusable Docker image and Docker build cache live in Docker Desktop's disk,
outside `.lab`. The installed image reports about 2.92 GB, including 2.25 GB
shared with its KiCad base. Normal test runs do not rebuild or grow this image.
Use `docker system df` to inspect storage. To remove this
project's image, use `docker image rm groundlark/lab:1` after tests have stopped.
Do not use global `docker system prune` or `docker volume prune` as project
cleanup: other projects, including Coldfoot, share this Docker installation.

## Moving or updating it

Clone the Git repository, or copy the authored project and environment directory
(excluding `.lab/` and `.local/`) to another machine,
then run `build`. No absolute `C:` or `P:` paths are encoded in the runner. The
image pins the KiCad base and uv installer by digest; atopile 0.15.9 and its
transitive Python dependencies are pinned with package hashes. Python is 3.14.7.
Device-tree compiler 1.6.1-4+b1 supplies real overlay compile/merge tests.
The KiCad base supplies KiCad 9.0.9 and ngspice 39; previous WSL validation used
ngspice 42. The reports explicitly record this difference.

For an offline transfer, optionally save a **single image archive**:

```powershell
docker save -o groundlark-lab-image.tar groundlark/lab:1
# On the receiving machine:
docker load -i groundlark-lab-image.tar
```

Keep that archive on transfer storage, not in the source repository or `.lab`.
Source plus an exported image gives a stronger toolchain snapshot than rebuilding
from online registries. Container runtime/kernel versions still vary by host.
The checked-in `requirements.lock` is consumed directly; the old project venvs
are never copied. `installed-constraints.txt` records the versions used when
creating that lock. Update pins deliberately and rerun the complete suite.

An [inactive GitHub Actions template](../environment/ci/README.md) can run the
structure checks, cleanup tests, and full hardware profile on pushes and pull
requests, with report retention of seven days. It has not been installed because
the current GitHub login lacks workflow-management scope. The local suite is
fully usable. The software/full/quick profiles validate the sensor application,
contracts, framing, recording/replay and bounded recovery. MCU firmware and
physical device behavior remain outside these checks.
Buf 1.73.0 is downloaded only during image build and SHA-256 checked; Protobuf
5.29.6 reuses the existing Python lock. Runtime tests remain offline.

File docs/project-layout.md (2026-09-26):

# Project organization

| Location | Purpose |
| --- | --- |
| `hw/ato.yaml` | Three atopile build targets: ASIC HAT, USB field head, Trenz HAT. |
| `hw/elec/` | Electrical source and atomic part definitions. |
| `hw/layout/`, `hw/layout*.json` | Compiled connectivity and mechanical placement inputs. |
| `hw/boards/` | Routed KiCad projects, review schematics, BOMs, 3D previews and recorded validation. |
| `hw/releases/` | Ignored local manufacturer review packages with explicit release status and hashes; not published without an explicit request. |
| `hw/libraries/`, `hw/models/` | Shared KiCad symbols/footprints and local 3D models. |
| `hw/tools/`, `hw/tests/`, `hw/simulation/` | CAD tooling, electrical fault fixture, bounded SPICE models and recorded results. |
| `hw/reference/`, `hw/vendor/` | Component references and upstream board material. |
| `sw/interfaces/` | Versioned Protobuf, compatibility baseline, reference validation/framing. |
| `sw/tools/` | Offline schema and software check entrypoint. |
| `sw/pi/` | Pi drivers/configuration, acquisition, calibration and recording/replay. |
| `sw/field-head/` | Planned USB microcontroller firmware. |
| `sw/fpga/` | Trenz SPI echo bitstream, host-link checks and board constraints. |
| `sw/tests/` | Contract, acquisition, recording, recovery and FPGA-link tests. |
| `sw/ui/` | Python/NiceGUI workbench, locked optional dependencies and display assets. |
| `docs/` | Setup, hardware specifications, assembly, interface contracts and testing instructions. |
| `environment/` | Pinned portable toolchain, launcher implementation and safeguard tests. |
| `.lab/` | Ignored disposable reports, bounded by retention. |
| `.local/` | Ignored local dependencies and preserved legacy caches. |

Run the root `lab.ps1` / `lab.sh` commands from any working directory. Low-level
commands documented elsewhere assume the repository root as the working directory.
The atopile project itself is now `hw/`, so direct builds must target that directory.

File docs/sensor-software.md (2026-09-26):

# Sensor acquisition and recovery

**New to the simulator?** Start with the [browser workbench walkthrough](sensor-workbench.md).
This page covers command-line development and real Linux acquisition.
The current HAT has three IMUs and a Racotech geophone input; GNSS and the
inclinometer are removed. Legacy drivers remain for older recordings/tests.

The runnable Pi application is in `sw/pi/groundlark/`; use
`sw/tools/sensor.py` as its repository entry point. It has no FPGA, Coldfoot,
network service or database dependency. Simulation and Linux device adapters
use the same scheduler, calibration, session validation and recording path.
Physical acceptance follows the [bench procedure](bench-procedure.md).

## Run without hardware

Run `./lab.ps1 test -Profile software` (or `sh ./lab.sh test --profile software`).
The portable environment contains the pinned Python/Protobuf and Buf tools.
It builds the descriptor, runs tests, executes a two-second six-sensor fault
scenario and replays it. Retained outputs are under
`.lab/runs/<run-id>/results/sw/build/`: `demo.ssrec`, `demo-summary.json` and
`verification.json`. Five-run retention and existing cleanup cover these files.
No new environment or global package installation is needed for this workflow.

For direct development use Python 3.12+ with the Protobuf version in
`environment/requirements.lock`, and Buf 1.73.0. Generate the descriptor once:

```sh
mkdir -p sw/build
buf build sw/interfaces --exclude-source-info -o sw/build/schema.binpb
python sw/tools/sensor.py simulate --remote --seconds 2 \
  --faults sw/tests/fixtures/acquisition_faults.json --output sw/build/my-run.ssrec
python sw/tools/sensor.py replay sw/build/my-run.ssrec
```

Outputs use exclusive creation: choose a new filename for each direct run.
The lab manages its own copy and does not delete direct developer recordings.
`GROUNDLARK_DESCRIPTOR` can select a descriptor outside the default build
directory. Do not use the frozen compatibility baseline as the generated schema.

The scenario is deterministic for a given seed, configuration and fault file,
including recording bytes. It covers three IMUs, geophone,
magnetometer and pressure. Remote streams in this command are modeled MCU
producers, not firmware or USB emulation. Separate tests send framed messages
in fragments through a Linux pseudo-terminal. `--queue 1 --drain-every 100`
exercises a slow consumer. Simulated time starts at zero; Pi and remote clocks
retain distinct domains even when numerically equal.

Virtual sensors use controllable motion, magnetic, pressure and geophone
[stimulus models](stimulus-models.md). Pass `--scenario` for saved waveforms and
timed controls; `export-scenario` recovers controls from a recording. Without a
scenario, sensors start stationary and level, with a constant magnetic field,
zero differential pressure and zero geophone velocity.

## Linux device adapters

The live path uses Linux SPI/I²C ioctls, GPIO character-device line requests,
and a nonblocking USB CDC TTY. The initial profile is:

| Sensor | Configuration and reading |
| --- | --- |
| Three LSM6DSO | 26 Hz, ±2 g, ±250 dps; identity/reset/readback; BDU/address increment; signed temperature, gyro and acceleration. |
| ADS122C04 geophone input | I²C 0x40; 330 SPS, PGA64, internal 2.048 V reference; signed 24-bit counts, conversion counter and inverted-data integrity checks. |
| USB head | Receive v1 identity/configuration/batches/status over framed CDC; real firmware is still required. |

SCL3300 and MAX-M10S code is retained for legacy use and is not part of the
current HAT profile. GNSS/PPS references later in this guide concern that legacy path.

Copy [the example profile](../sw/pi/profiles/daqhat-01.example.json) and verify paths
on the actual Pi. `gpiochip0` is an example, not an assertion about Pi 5 GPIO
numbering. `line` is the character-device offset corresponding to BCM26 on that
chip. The application owns active-low sensor output enable and disables it on
normal/error cleanup.

| Signal | BCM GPIO | Physical header pin |
| --- | --- | --- |
| SPI0 MOSI / MISO / SCLK | 10 / 9 / 11 | 19 / 21 / 23 |
| IMU1 / IMU2 / IMU3 chip select | 8 / 7 / 5 | 24 / 26 / 29 |
| Spare, unconnected (former inclinometer CS) | 13 | 33 |
| Sensor buffer OE, active low | 26 | 37 |
| Geophone ADC I²C SDA / SCL | 2 / 3 | 3 / 5 |

The [Pi 4 deployment package](../sw/pi/deploy/README.md) now supplies the three-CS
overlay, 100 kHz I²C configuration and an identity-checked `driver_override`
binding tool. Its compiled overlay is merge-tested in the portable lab. The
selected physical Pi/kernel must still be boot-tested. No overlay is installed
automatically and no unrelated kernel device is detached.

```sh
python sw/tools/sensor.py live --profile sw/pi/profiles/daqhat-01.example.json \
  --seconds 60 --output sw/build/bench-001.ssrec
# Add --usb /dev/serial/by-id/<actual-head-id> when head firmware is ready.
```

Startup fails closed: every local sensor must identify and confirm settings
before effective-configuration advertisements. Live boot IDs are random per
acquisition process. The application never accesses FPGA UART, JTAG, reset or
GPIO expansion.

These drivers have modeled-bus verification, not bench qualification. Polling
timestamps represent read completion using `CLOCK_MONOTONIC_RAW`; conversion
uncertainty and physical overwritten-conversion counts are unknown. Live
batches omit `dropped_before`. Sequences count scheduled application slots;
overdue slots are skipped and unavailable scheduled samples are MISSING.
Do not infer lossless acquisition or synchronized devices from polling time.
The optional FIFO path below replaces these polling semantics for the IMUs.
Sensor self-test qualification, board-axis transforms and
GNSS fix decoding in the live CLI remain follow-on work. Legacy SCL3300
register reads are sequential, not an atomic six-axis snapshot.

## Buffered IMUs and PPS capture

Add `--fifo` to the live command with the updated DAQHAT-01 profile. Three rising-edge
GPIO requests use BCM27/22/23. FIFO watermark/overrun interrupts are hints;
a 20 ms periodic service interval also checks each FIFO. SPI transfer work is
limited to 96 seven-byte records (32 complete IMU slots) per call. A larger
backlog, hardware overrun, bad tag parity, unexpected sensor/configuration tag,
duplicate field or missing slot discards the drain, resets the FIFO and records
an overflow/error status and a MISSING marker. The existing finite restart policy
still applies. Normal scheduling delays do not discard buffered conversions.

Each sample pairs the acceleration, gyro and timestamp tags by their two-bit
slot counter. The 32-bit 25 μs device timestamp is mapped to a bracketed RAW-clock
read of the current device counter. Wrap is handled modulo 2^32; stale, future,
duplicate or backward timestamps are rejected. Unknown filter delay, oscillator
error and absolute mapping accuracy remain unqualified, so uncertainty is absent.
The raw six-axis counts are retained; no same-slot temperature is invented.
Use the polling path for temperature characterization. FIFO calibration artifacts
must therefore omit temperature and use the FIFO effective-configuration hash.

FIFO sequences enumerate delivered samples and explicit missing markers, not
all physical conversions. Physical losses remain unknown (`dropped_before`
absent), including after a FIFO flush; output queue losses remain accounted for.
No samples are emitted for a healthy empty FIFO. Acquisition shuts down rather
than continue using a failed GPIO event descriptor.

BCM4 PPS edges are recorded as events with the original kernel MONOTONIC time,
an estimated RAW time and the clock-mapping read bracket. A bracket is not total
timestamp uncertainty. No UTC value is assigned from receipt time or an assumed
NAV-PVT-to-pulse relationship. Add `--utc` to configure/read back the receiver's
timepulse and collect timing messages. [Offline UTC correlation](utc-timing.md)
creates a separate recording using explicit, recording-bound timing-error limits.
It preserves raw timestamps and omits UTC across ambiguous or unbounded intervals.

Reference: [ST AN5192, FIFO tags and timestamp correlation](https://www.st.com/resource/en/application_note/DM00517282-.pdf).

## Stationary bench analysis

`python sw/tools/measure_hat.py sw/build/bench-001.ssrec --output
sw/build/bench-001.json` streams a recording through contract/session validation
and reports per-axis mean, standard deviation, peak-to-peak, linear drift per
second, gravity magnitude, sample intervals, sequence gaps and quality counts.
PPS events produce interval statistics. Values use advertised nominal sensitivity
in package axes; no measured calibration or physical PASS is fabricated.

Repeat the same stationary acquisition with the FPGA off, idle and active.
Use `--baseline sw/build/off.ssrec` while analyzing idle/active recordings to
report mean changes and noise ratios. A zero-noise baseline yields an unknown
ratio, not infinity or a passing result. Configuration mismatches and incomplete
comparisons are rejected. These statistics require controlled test conditions;
standard deviation is not noise spectral density or an Allan-deviation analysis.

## Recovery and bounds

Each local device runs in one supervised process with one outstanding request.
A read deadline is 250 ms; configuration has four seconds. Termination and kill
each get a 100 ms reap window. An unreaped worker prevents replacement instead
of spawning more workers. Host deadlines cannot repair an uninterruptible
kernel or a physically stuck bus.

Three consecutive I/O failures or one timeout put a channel offline. It emits
MISSING samples, waits one second and attempts at most two reconfigurations in
that run. Data-not-ready is a polling miss, not a reset trigger. Recovered
settings must match the recorded configuration. Exhausted channels stay offline
until a new run. Status messages explain failures and recovery.

Geophone conversion discontinuities are separate from I/O failures: the bus can
be healthy while the host misses ADC conversions. `DataGap` survives worker IPC,
emits a discontinuity status and MISSING record with unknown loss, and clears the
consecutive I/O-failure count. It does not reset the ADC. Duplicate reads do not
extend the counter-wrap ambiguity timer. Current polling does not preserve every
conversion under modeled load; exact sample timing and lossless capture are not
qualified. Follow the [bench procedure](bench-procedure.md) for physical measurements.

The queue defaults to 64 batches (configurable 1–4096). It drops newest data on
overflow, carries known/unknown loss into the next accepted batch and retains
a final summary of losses without subsequent batches. Control messages drain
older data first and are never silently dropped. Recording retains arrival
order. A process/file failure may leave an incomplete recording.

USB chunks are at most 4096 bytes; framing has the
[contract's byte bounds](sensor-contract.md#usb-cdc-framing-and-bounds).
Partial frames expire after one second and discard through the next delimiter.
CRC, malformed Protobuf, semantic and session failures are counted and recorded.
USB permits eight open attempts per run, one second apart. Reconnect requires
identity/configuration again without erasing sequence history. USB only accepts
head identities and reserves the local Pi ID. CRC is not authentication.

Sessions retain at most four producers and 32 retired boot IDs per producer.
New boots may restart clocks/sequences. Retired boots, duplicates, backward
timestamps, contradictory known loss, stale configurations and decreasing loss
totals are rejected. Reaching a capacity requires a new recording.

## Calibration and recordings

`--calibrations` accepts a JSON list of at most 16 artifacts. Each has
`sensor_id`, `configuration_sha256`, `provenance` and `fields`. SHA-256 binds
the deterministic serialized `SensorConfiguration`, including read-back
register settings, to coefficients. Each field has explicit `scale` and `offset`
arrays (three values for vectors, one for scalars). The operation is
`SI = raw × scale + offset` in package axes; field names declare SI units.
Record the method, reference and date in `provenance`. Physical calibration
is supplied by the user, never invented by the application.

Inputs are acceleration, gyro, tilt angle, magnetic counts, IMU/tilt temperature
and DLVR 14-bit pressure counts. Finite results and sensor/field compatibility
are checked. GNSS and pressure-response temperature conversion are not
implemented. Raw values remain unchanged. The content hash becomes the
calibration ID; full artifacts are stored with recordings. Only VALID/SATURATED
samples receive calibrated values.

The streaming `.ssrec` format is `SSREC01\0`, a little-endian 32-bit JSON-header
length, header JSON, then CRC32 over magic/length/JSON. Each record contains a
little-endian `(uint8 kind, uint64 arrival_ns, uint16 length)` prefix, payload,
and CRC32 over prefix/payload. Kind 1 holds a complete delimited v1 frame;
kind 2 holds a JSON event. Metadata is bounded to 16 KiB, record payloads to
2048 bytes, and files to 64 MiB by default (up to 1 GiB). Budget exhaustion
stops acquisition with an error. There is no silent rollover or in-memory list
of a whole recording.

Replay streams records, validates CRC/order/contracts/sessions/calibration
references and computes a digest of message bytes. A final `acquisition_summary`
event marks normal completion. A complete prefix without that event is readable
but incomplete; partial/corrupt records fail. USB arrival time never replaces
remote acquisition time.

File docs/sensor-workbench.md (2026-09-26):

# Run your first Groundlark sensor experiment

The sensor workbench is a local browser app for trying virtual sensors and
replaying recordings. Click the 3D HAT or geophone, change an input, and watch
its signal. **No Raspberry Pi or sensor hardware is required.**
The header uses the same lark-and-waveform wordmark as the project README.

You need internet access for setup, a modern browser with WebGL, and Windows
PowerShell or a Linux/macOS terminal. The scripts install the needed Python
tools locally. Docker, KiCad, Node.js and an FPGA are not prerequisites.

Workbench showing the geophone and a simulated 2 Hz signal

## 1. Get the project

If you already have the project folder, use it. Otherwise visit the
[Groundlark repository](https://github.com/crockpotveggies/groundlark), choose
**Code → Download ZIP**, and extract it to a folder you can write to.
Git users can instead run `git clone https://github.com/crockpotveggies/groundlark.git`.

Open a terminal in that folder. You should see `README.md`, `setup-ui.ps1` and
`setup-ui.sh`. On Windows, right-click the folder and choose **Open in Terminal**,
using a PowerShell tab. On macOS/Linux, use `cd` followed by your folder's path;
quote paths that contain spaces.

## 2. Set up once, then start

**Windows — PowerShell:**

```powershell
./setup-ui.ps1 -Check
./ui.ps1
```

**Linux/macOS — Terminal:**

```sh
sh ./setup-ui.sh --check
sh ./ui.sh
```

Setup downloads a pinned uv tool from its official source and installs the
locked Python dependencies. The check option starts a temporary server,
checks the page and assets, and tests the geophone scene. Wait for the checks
to pass; the first download may take a few minutes. Rerunning setup is safe.

Once the launch command reports the server is ready, open
**[http://127.0.0.1:8080](http://127.0.0.1:8080)**. Keep the terminal open while
using the app. **Ctrl+C** in that terminal stops it.
Next time, just run `./ui.ps1` or `sh ./ui.sh` again.

If PowerShell blocks scripts, follow your computer's approved process for
running local development scripts. On a managed computer, ask your administrator.
The project does not need administrator privileges or a permanent policy change.

## 3. Make a geophone signal

1. Click **Geophone** in the device list or the gold can in the 3D view. The can
   and its HAT input highlight together: they represent one signal.
2. Expand **Geophone stimulus** on the right (below the charts on a narrow screen).
3. Set **Vertical velocity amplitude** to **100** µm/s and **Frequency** to **2** Hz.
4. Press **Apply geophone tone**, then **Start** in the top bar.
5. After a few seconds, press **Pause**. Look for a repeating wave in
   **Geophone ADC · raw counts** and a **Valid** status.

Changing a box alone does not change the experiment: press its **Apply** button.
The geophone has one vertical channel. The chart shows ADC counts, not velocity
units. Zero motion produces a flat ideal trace. The model includes nominal
geophone response, but not real noise or settling. The chart retains recent
points; the recording contains the whole run.

## 4. Try the other sensors

Click **Load rocking + field demo**, then **Start** to explore IMU and remote-head
signals. This replaces the current run, so save first if needed.

| Control | What to look for |
| --- | --- |
| **Pose & vibration** | Select an IMU; tilt moves gravity between XYZ axes, and vibration adds an oscillation. A stationary IMU still measures gravity. |
| **Magnetic field & infrasound** | Select Magnetometer or Infrasound to view the separate USB head and its modeled signals. |
| **Fault injection** | Apply a sensor fault and inspect status, events and missing-data gaps. Start a new run to return to a clean baseline. |
| **Top / Orbit**, drag, scroll | Change the camera only. These gestures do not stimulate sensors or change recorded samples. |

The HAT has three IMUs and one geophone input. The optional remote head adds
magnetometer and pressure streams: six sensor streams altogether.

## 5. Save and replay

- **Finish & save** ends the capture and downloads a `.ssrec` recording to your
  browser's download location. It includes samples and applied input changes.
- Under **Recordings & scenarios**, upload that recording. Press **Play** or
  move the timeline slider to inspect it.
- In replay mode, stimulus controls are disabled because the samples already
  exist. Use **New run** to create a new experiment.
- **Export scenario** saves inputs as JSON. Import it with the same seed to
  repeat the experiment. See [advanced scenarios](stimulus-models.md).

**Save before refreshing, closing the tab or starting a new run.** Experiments
live in memory, independently in each tab. There is no automatic save database.
A capture stops at three simulated minutes or its 8 MiB limit.

## 6. Run the built-in HAT check

Save your experiment, then press **Test HAT signals**. The app runs eight seconds
of modeled input through the production HAT drivers and opens the capture in
replay. Expect **nine passing checks** covering **3,264 samples** from the three
IMUs and geophone input. Expand the results for measurements and tolerances;
download the recording and JSON report from that panel.

This checks driver and recording behavior on modeled buses. It does not prove
physical power, fit, timing, noise, sensor accuracy or FPGA operation. The browser
currently simulates and replays; it does not connect to a real HAT. For real Pi
acquisition, use the [Linux software guide](sensor-software.md).

## Troubleshooting

| Symptom | What to do |
| --- | --- |
| Setup cannot download packages | Check your internet/proxy settings and retry setup. Keep TLS verification enabled. |
| `uv` or Python is missing | Run setup; no separate Python install is needed. |
| Browser cannot connect | Keep the launcher terminal open, wait for the ready message, and check errors printed there. |
| Port 8080 is already in use | Run `./ui.ps1 -Port 8081` or `sh ./ui.sh --port 8081`, then open `http://127.0.0.1:8081`. |
| 3D area is blank | Enable WebGL/hardware acceleration or try another current browser. Run `./ui.ps1 -Check` / `sh ./ui.sh --check` to check asset delivery separately. |
| Flat or empty chart | Select the intended sensor, press **Apply**, then **Start**. Check status and faults. Paused or unexcited sensors may correctly stay flat. |
| Changes seem ineffective | Press **Apply**. Stimulus controls are unavailable during replay. Camera gestures never stimulate sensors. |
| Recording will not open | Keep the original file. The app rejects corrupt data; an incomplete recording may show a completion warning, while a corrupt one is rejected. |
| Board visualization is stale | Use matching code/CAD/assets from the same checkout. Contributors should follow [asset provenance](../sw/ui/assets/README.md). |

## Storage and cleanup

Setup stores its tools under ignored `.local/`: uv, Python when needed, virtual
environments and the package cache. It leaves your persistent PATH and circuit
design environment unchanged. Windows and Unix use separate environments.
Startup generates the schema in ignored `sw/build/ui-schema.binpb`.
Experiments create no run folders; browser downloads remain separate.

To reclaim only the package download cache, stop the app and run:

```powershell
# Windows
./.local/tools/uv-windows/uv.exe cache clean --cache-dir .local/uv-cache
```

```sh
# Linux/macOS
./.local/tools/uv-unix/uv cache clean --cache-dir .local/uv-cache
```

Dependencies may need downloading again afterward. Keep other `.local/` files:
they can include project tools and manually saved results.
After updating the repository, rerun setup with its check option.

## For contributors

See [sensor software](sensor-software.md) for data and timing semantics and
[UI source notes](../sw/ui/README.md) for checks and asset provenance.
The [portable lab](portable-lab.md) is the separate Docker-based full regression
environment; it is optional for using this UI.
Setup uses the official [uv installer options](https://docs.astral.sh/uv/reference/installer/)
with an unmanaged local install and the checked `sw/ui/uv.lock`.

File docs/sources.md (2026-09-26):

# A2 design evidence and provenance

Reviewed 2026-09-23. These references support component selection and pin assignments; they are not evidence that the assembled design has been validated.

| Reference | Use |
|---|---|
| [AnyShake](https://github.com/anyshake) and [GeoShake](https://github.com/GeoShake) | Related open-source seismic acquisition projects |
| [wafer.space pinned run-1 module](https://github.com/wafer-space/chip-on-board-wire-bonded-pcbs/tree/90fc89d65ef5ee5d9beb64b12b9cc8fa4ced7f08/run-1) | Selected 1×1 module connector nets and mating footprint |
| [ST LSM6DSO datasheet](https://www.st.com/resource/en/datasheet/lsm6dso.pdf) | 14-pad package, primary SPI mode connections and supply bypassing |
| [Murata SCL3300-D01 datasheet](https://www.murata.com/-/media/webrenewal/products/sensor/pdf/datasheet/datasheet_scl3300-d01.ashx?la=en) | 12-pin assignment, external regulator capacitors, land pattern and SPI requirements |
| [u-blox MAX-M10S integration manual](https://content.u-blox.com/sites/default/files/MAX-M10S_IntegrationManual_UBX-20053088.pdf) | 18-pin assignment, 3.3 V I/O selection, I2C/PPS and RF integration |
| [PNI RM3100 breakout manual](https://www.pnisensor.com/wp-content/uploads/RM3100-Breakout-Board-User-Manual-r07.pdf) | Complete PNI 14190 module, I2C strap pins, row spacing, axis conventions and magnetic measurement behavior |
| [All Sensors DLVR DS-0300](https://www.allsensors.com/hubfs/Product-Data-Sheets/DS-0300.pdf) | Pressure range, E1BS package, digital interface and ordering-code options |
| [Raspberry Pi HAT+ specification](https://pip-assets.raspberrypi.com/categories/1215-raspberry-pi-hat/documents/RP-008281-DS-1-hat-plus-specification.pdf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) | Header ID bus, standby power-state requirements and EEPROM expectations |
| [KiCad Raspberry Pi HAT template](https://github.com/KiCad/kicad-templates/tree/master/Projects/raspberrypi_hat) | Reference outline and header/mounting-hole geometry; snapshot in `hw/reference/` |

Selected PDFs are cached under `hw/reference/`, together with extracted text and selected mechanical illustrations. Supplier datasheets retain their owners' copyright. Do not infer a redistribution license from their inclusion as working references.

The wafer.space source files are unmodified reference copies and retain the upstream Apache-2.0 `LICENSE`. A2 uses the selected run-1 mating footprint from its example motherboard, with documented coordinate normalization. Standard footprints come from KiCad; the license notice is retained in `hw/libraries/KICAD-COPYRIGHT`. Custom sensor footprints follow the named supplier drawings; simplified 3D envelopes are project-authored and are not supplier-certified models.

Freerouting 1.9.0 is from [the upstream release](https://github.com/freerouting/freerouting/releases/tag/v1.9.0). A2 uses atopile 0.15.9, KiCad 9.0.9/pcbnew, ngspice and Python under WSL Ubuntu 24.04. Tool environments and jars are local dependencies, not authored design files.

## A2 additional primary references

- [Run-1 module and pin convention](https://github.com/wafer-space/chip-on-board-wire-bonded-pcbs/tree/90fc89d65ef5ee5d9beb64b12b9cc8fa4ced7f08/run-1): module PCB and example motherboard footprint.
- [HCTL receptacle drawing](https://datasheet.lcsc.com/datasheet/pdf/f2ef933153da158dccaefb106ab7c3d4.pdf): 70 contacts, 0.4 mm pitch, mating heights and 300 mA/contact.
- [TI TLV1117LV](https://www.ti.com/lit/ds/symlink/tlv1117lv.pdf): sensor supply, pinout, ceramic capacitor requirements and thermal data.
- [TI SN74LVC8T245](https://www.ti.com/lit/ds/symlink/sn74lvc8t245.pdf): partial-power-down GPIO isolation, direction/OE behavior.
- [TI ISO1640](https://www.ti.com/lit/ds/symlink/iso1640.pdf): I2C domain isolation and offset low-output thresholds.
- [TI TXU0202](https://www.ti.com/lit/ds/symlink/txu0202.pdf): fixed opposing UART directions, OE and disconnected-supply behavior.
- [TI TLV803E](https://www.ti.com/lit/ds/symlink/tlv803e.pdf): supervisor pinout, 3.0 V threshold and 200 ms delay selection.
- [Diodes AP63203](https://www.diodes.com/datasheet/download/AP63200-AP63201-AP63203-AP63205.pdf): buck topology, bootstrap capacitor, output capacitance and inductance range.
- [Bourns SRN6045TA](https://www.bourns.com/docs/product-datasheets/srn6045ta.pdf): selected 4.7 uH inductor, DCR, saturation/current limits and footprint.
- [Abracon ASE](https://abracon.com/Oscillators/ASEseries.pdf): 25 MHz oscillators, pinout, voltage and timing limits.
- [ST USBLC6-2](https://www.st.com/resource/en/datasheet/usblc6-2.pdf): cable-line transient steering and pinout.
- [Atopile source](https://github.com/atopile/atopile): pinned 0.15.9 atomic-part/build/solver API inspected locally. Numeric solving is explicitly invoked because this design uses manually selected parts.

The Coldfoot references are the user's existing sibling `coldfoot_soc` workspace, including uncommitted current implementation state. They have not been copied as a new chip specification or modified by this task. See [the integration note](coldfoot-integration.md) for paths and limitations.

## A2 USB sensor head

See [USB circuit and manufacturer references](usb-sensor-head.md). The former PCA9615 cable has been removed from both boards.

## DAQHAT-01 GPIO expansion

- Trenz exact-SKU revision-03 schematic, page 6, archived under `docs/vendor/trenz`:
  source for `trenz-gpio-module.csv` and `trenz-ground-module.csv`.
- [Amphenol F32Q 40-contact connector](https://www.amphenol-cs.com/product/f32q1a7h111040.html)
  and [60-contact connector](https://www.amphenol-cs.com/product/f32q1a7h111060.html):
  0.5 mm pitch, upper contacts, 2 mm nominal height.
- Footprints copied from KiCad 9 `Connector_FFC-FPC.pretty`, Amphenol F32Q family;
  mechanical MP tabs renumbered 41/61 for atopile and grounded. Library footprint
  geometry is retained. The separate FFC 3D bodies are simplified envelopes,
  not manufacturer STEP models or cable-clearance certification.

Conventional fabrication references: [JLCPCB capabilities](https://jlcpcb.com/capabilities/Capab) and [six-layer POFV](https://jlcpcb.com/news/free-via-in-pad-6-20-layer-pcbs-pofv). DAQHAT-01 uses stock six-layer FR-4 with 0.3 mm through-drills; supplier DFM and physical signal-integrity qualification remain separate.

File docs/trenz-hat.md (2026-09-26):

# Groundlark DAQHAT-01 — Pi-outline Trenz carrier

The front silkscreen carries a 7 mm monochrome Groundlark lark/waveform above
the model name. It is native KiCad polygon artwork, included in layout rebuilds
without adding BOM parts. See the [current 3D view](../hw/boards/groundlark-daqhat-01/3d.png).

**DAQHAT-01 revision:** six internal QSPI-reserved wires, retained UART and
switched Pi-driven JTAG replace external expansion connectors and ribbons.
See the [host-link circuit and bring-up guide](fpga-host-link.md). Pi 4 initially
uses SPI6; native quad transfers are not supported by its controller.

An external Racotech vertical geophone uses an ADS122C04 input; GNSS is not fitted.
See the [geophone circuit and acquisition](geophone-input.md).

DAQHAT-01 is an **85 × 56 mm, six-layer FR-4** alternative to the A2 Coldfoot ASIC HAT.
Electrical source: [`hw/elec/hat_trenz.ato`](../hw/elec/hat_trenz.ato).
CAD: [`groundlark-daqhat-01.kicad_pcb`](../hw/boards/groundlark-daqhat-01/groundlark-daqhat-01.kicad_pcb).
The original ASIC HAT and remote USB sensor head remain separate builds.

## Stack and sensor placement

From bottom to top: Raspberry Pi, Groundlark DAQHAT-01, **TE0712-03-81I36-A**.
The FPGA stays on top for heatsink access. The HAT keeps the three LSM6DSO IMUs
and ADS122C04 geophone input; the dedicated inclinometer is removed. The magnetometer and optional infrasound
sensor stay on the separate USB head; they consume no HAT area.

The Trenz outline occupies HAT coordinates x=30–80, y=8–48 mm, measured from
the upper-left corner. Its mounting holes are (33,11), (77,11), (33,45), (77,45)
mm. Two 100-contact connectors and one 60-contact connector mate underneath it.
The selected 4 mm carrier and module connectors give an **8 mm surface gap**.
Use four matching M3 spacers. Components under the module are low-profile;
the tall service connectors are outside its outline.

The baseline CAD shows the Samtec ESQ-120-23-G-D bottom socket. Its body height is
16.129 mm. A **Samtec SSQ-120-02-G-D** 1:1 GPIO riser now adds 8.51 mm between
the Pi and J1, giving **27.18 mm nominal Pi-top to HAT-underside clearance** with
a 2.54 mm Pi header base. Its 4.93 mm square tails point into J1; the socket face
mates to the Pi. Use measured spacers/shims for actual seating, without forcing
the connector stack. The conceptual model and assembly BOM include this riser.

**The JLCPCB assembly selection for J1 is Megastar ZX-PM2.54-2-20PY / C7499354,
with an 8.5 mm body.** The baseline clearance above does not qualify that shorter
part. Confirm riser, pin engagement and spacer heights before assembly; see
[JLCPCB assembly](jlcpcb-assembly.md).

The three IMUs have matching XYZ axes and lie outside the FPGA outline:
U11 at (13,24), U12 at (24,24), and U13 at (13,36) mm. Their distance from the
FPGA outline is 17, 6 and 17 mm respectively. These planar distances do not
establish thermal or mechanical isolation. Local 100 nF bypass capacitors and
In1.Cu ground stitches are required. Connected-path limits checked by
`hw/tools/imu_layout.py` are 4 mm for VDDIO bypass, 2 mm for VDD bypass,
2 mm for capacitor ground and 2.5 mm for IMU ground-pin paths. These geometry
limits do not establish minimum noise; measure FPGA-off/idle/active coupling.

This compact stack increases thermal and electrical coupling compared with
placing the FPGA beside the Pi. Accelerometer/tilt drift and noise must be
measured with the FPGA idle and active, and cooling must avoid exciting the
motion sensors. Pi cooler compatibility needs a physical check.
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

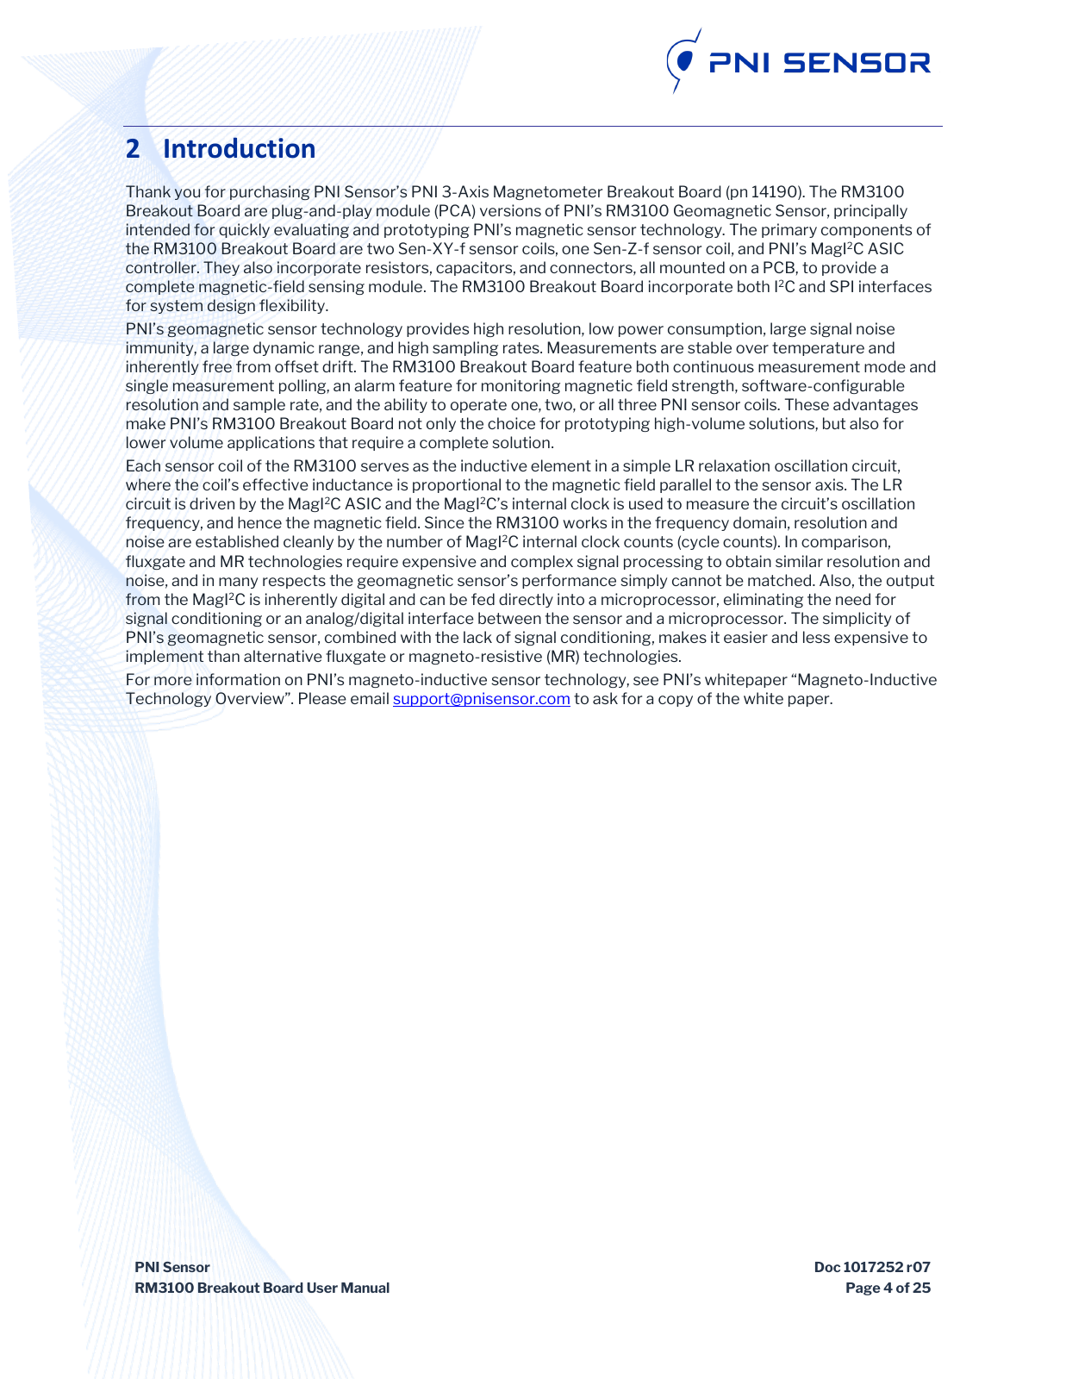
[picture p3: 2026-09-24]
hw/reference/rm3100-mechanical.png

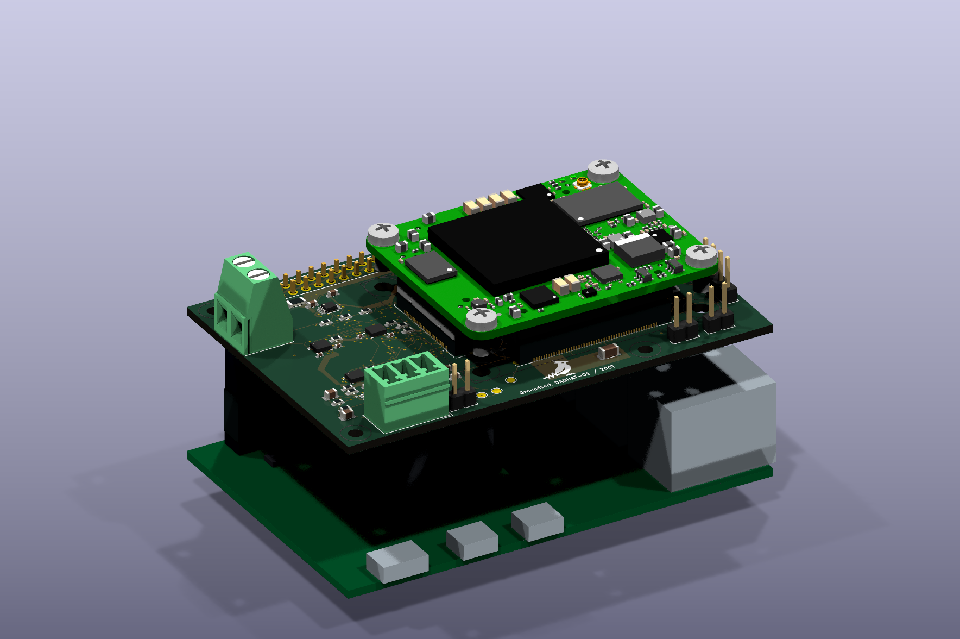
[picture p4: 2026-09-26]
hw/boards/groundlark-daqhat-01/pi-trenz-stack-concept.png

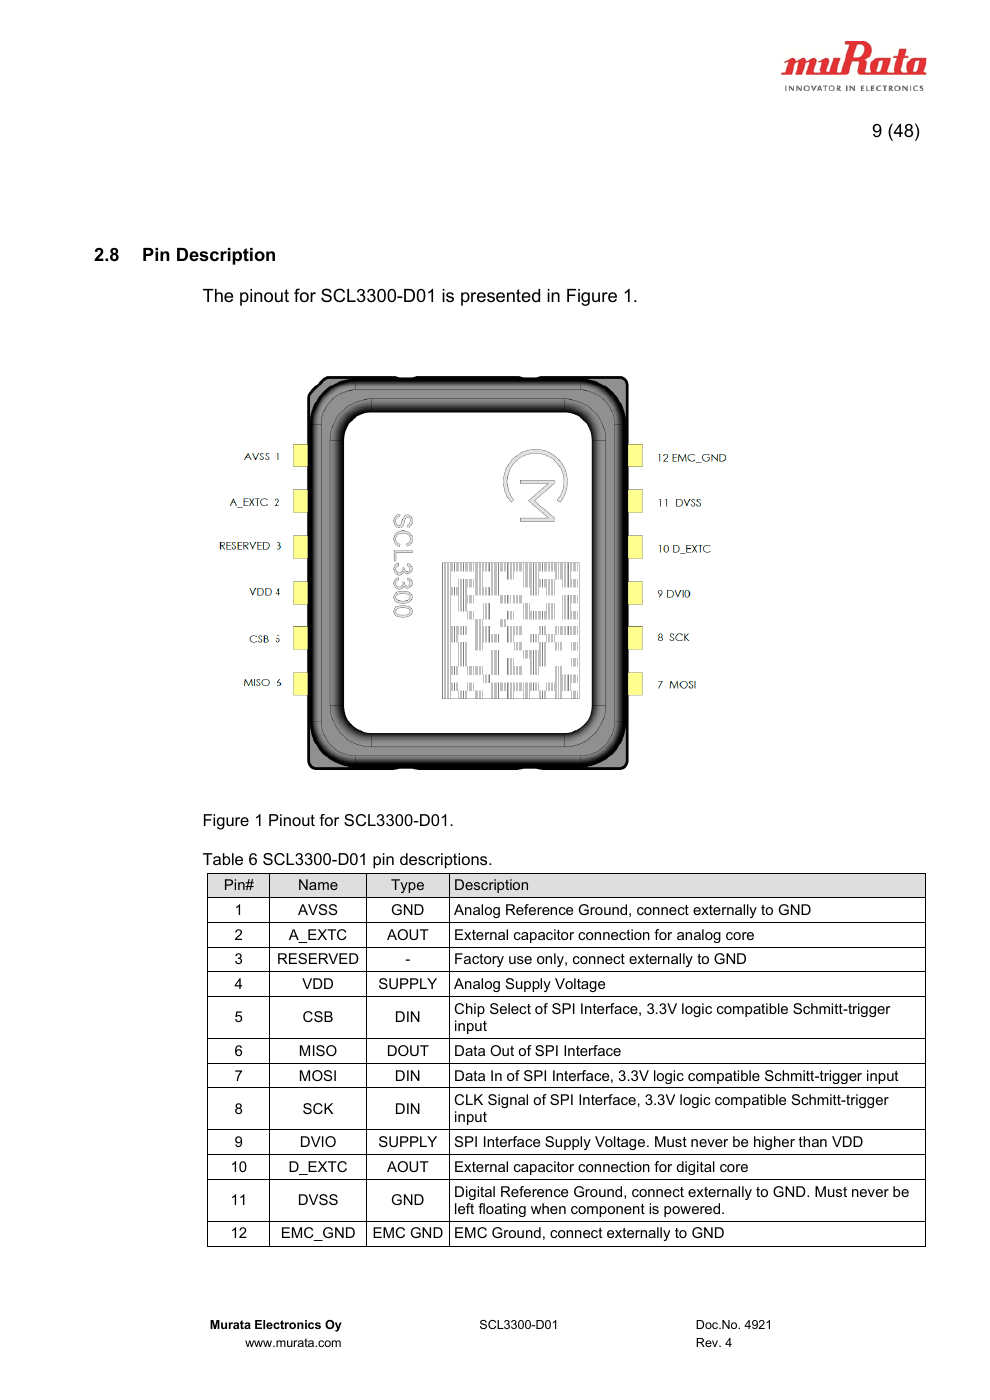
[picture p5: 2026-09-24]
hw/reference/scl3300-pinout.png

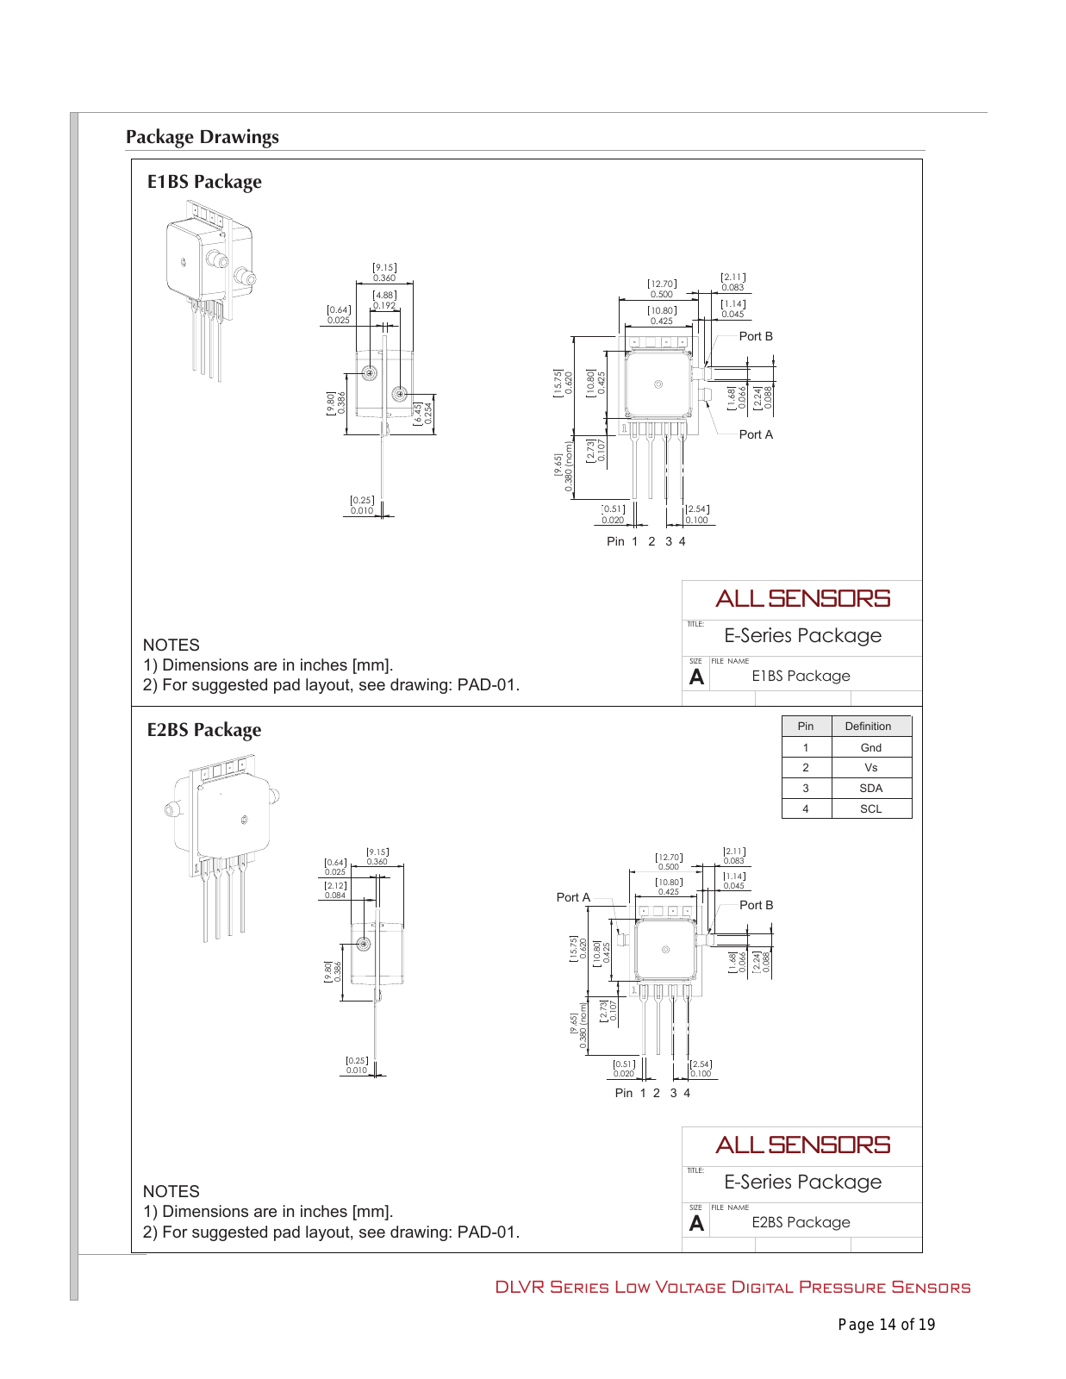
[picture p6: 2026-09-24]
hw/reference/dlvr-package.png

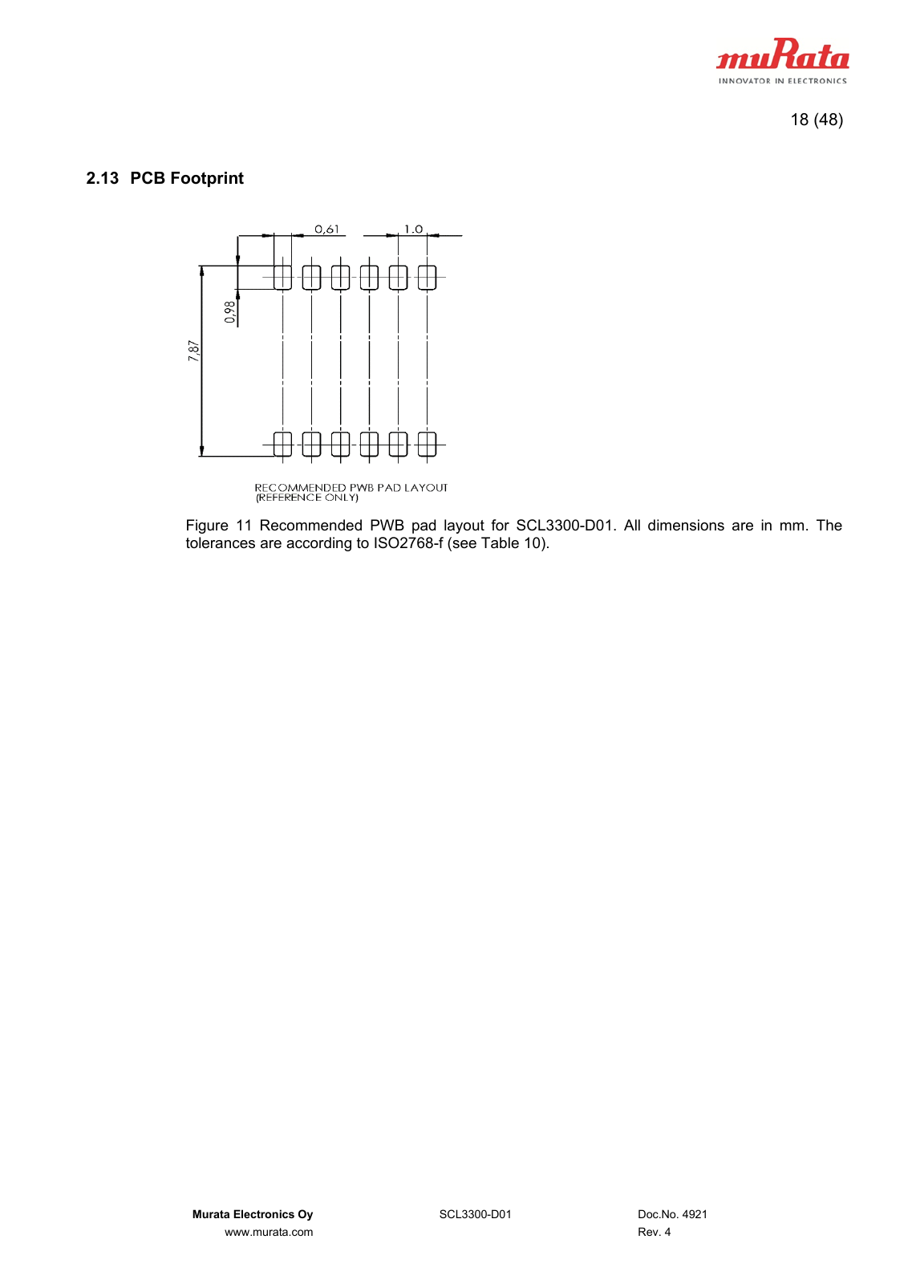
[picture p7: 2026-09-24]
hw/reference/scl3300-footprint.png

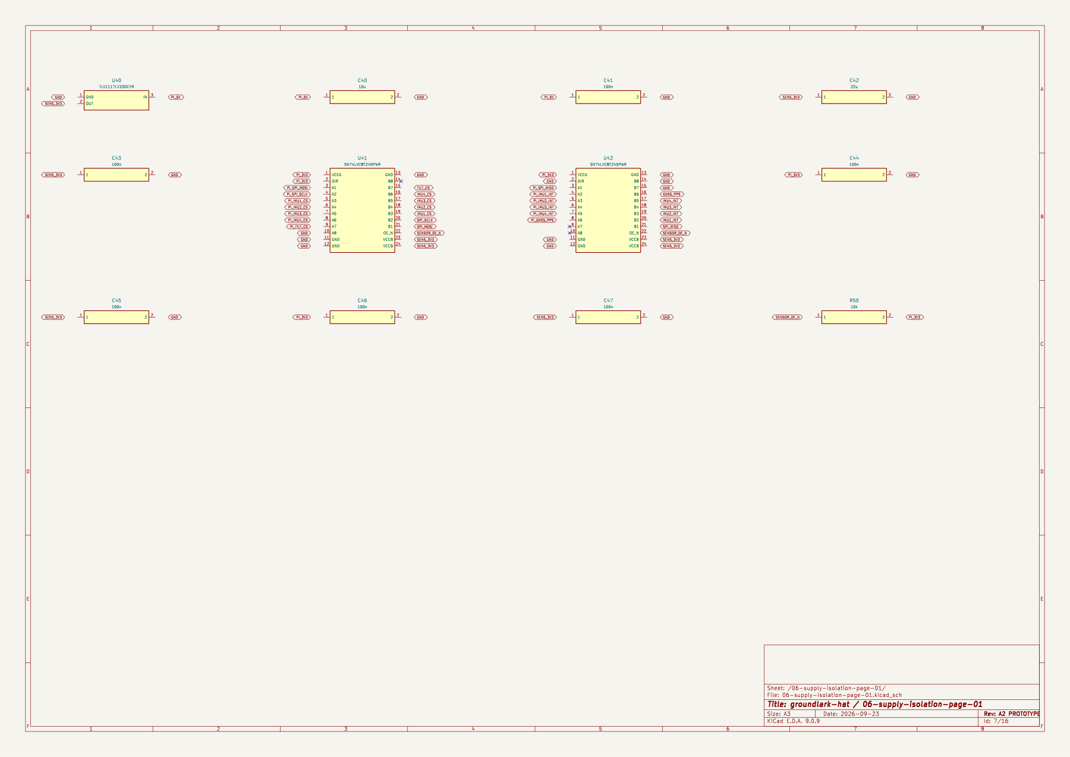
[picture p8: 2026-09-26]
hw/boards/groundlark-hat/preview/groundlark-hat-06-supply-isolation-page-01.png

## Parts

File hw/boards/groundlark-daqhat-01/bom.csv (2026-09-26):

Reference | Value | MPN | Footprint | DNP | Note
J1 | Raspberry Pi 40-pin | Samtec ESQ-120-23-G-D | Connector_PinHeader_2.54mm__PinHeader_2x20_P2.54mm_Vertical | False | Header land pattern matches bottom mounted socket top-view numbering; tall stack, check Pi 4/5 cooler clearance.
U1 | 24LC32A | 24LC32A-I/SN | Package_SO__SOIC-8_3.9x4.9mm_P1.27mm | False
R1 | 3.9k | RC0603FR-073K9L | Resistor_SMD__R_0603_1608Metric | False
R2 | 3.9k | RC0603FR-073K9L | Resistor_SMD__R_0603_1608Metric | False
R3 | 1k | RC0603FR-071KL | Resistor_SMD__R_0603_1608Metric | False
JP1 | EEPROM write enable | EEPROM write enable | Connector_PinHeader_2.54mm__PinHeader_1x02_P2.54mm_Vertical | False | Fit shunt only while programming ID EEPROM.
C1 | 100n | GRM188R71H104KA93D | Capacitor_SMD__C_0603_1608Metric | False
C2 | 10u | GRM21BR61A106KE19L | Capacitor_SMD__C_0805_2012Metric | False
C3 | 10u | GRM21BR61A106KE19L | Capacitor_SMD__C_0805_2012Metric | False
U11 | LSM6DSOTR | LSM6DSOTR | Package_LGA__LGA-14_3x2.5mm_P0.5mm_LayoutBorder3x4y | False
C12 | 100n | GRM155R71C104KA88D | Capacitor_SMD__C_0402_1005Metric | False
C13 | 100n | GRM155R71C104KA88D | Capacitor_SMD__C_0402_1005Metric | False
R11 | 10k | RC0603FR-0710KL | Resistor_SMD__R_0603_1608Metric | False
U12 | LSM6DSOTR | LSM6DSOTR | Package_LGA__LGA-14_3x2.5mm_P0.5mm_LayoutBorder3x4y | False
C14 | 100n | GRM155R71C104KA88D | Capacitor_SMD__C_0402_1005Metric | False
C15 | 100n | GRM155R71C104KA88D | Capacitor_SMD__C_0402_1005Metric | False
R12 | 10k | RC0603FR-0710KL | Resistor_SMD__R_0603_1608Metric | False
U13 | LSM6DSOTR | LSM6DSOTR | Package_LGA__LGA-14_3x2.5mm_P0.5mm_LayoutBorder3x4y | False
C16 | 100n | GRM155R71C104KA88D | Capacitor_SMD__C_0402_1005Metric | False
C17 | 100n | GRM155R71C104KA88D | Capacitor_SMD__C_0402_1005Metric | False
R13 | 10k | RC0603FR-0710KL | Resistor_SMD__R_0603_1608Metric | False
J4 | FPGA test UART/reset | Coldfoot UART service ONLY | Connector_PinHeader_2.54mm__PinHeader_1x04_P2.54mm_Vertical | False | Test points for assembled module UART and active-low reset; do not connect a second driving host.
H1 | M2.5 NPTH | M2.5 NPTH | MountingHole__MountingHole_2.7mm_M2.5 | False | Nonmagnetic standoffs.
H2 | M2.5 NPTH | M2.5 NPTH | MountingHole__MountingHole_2.7mm_M2.5 | False | Nonmagnetic standoffs.
H3 | M2.5 NPTH | M2.5 NPTH | MountingHole__MountingHole_2.7mm_M2.5 | False | Nonmagnetic standoffs.
H4 | M2.5 NPTH | M2.5 NPTH | MountingHole__MountingHole_2.7mm_M2.5 | False | Nonmagnetic standoffs.
U40 | TLV1117LV33DCYR | TLV1117LV33DCYR | Package_TO_SOT_SMD__SOT-223-3_TabPin2 | False
C40 | 10u | GRM21BR61A106KE19L | Capacitor_SMD__C_0805_2012Metric | False
C41 | 100n | GRM188R71H104KA93D | Capacitor_SMD__C_0603_1608Metric | False
C42 | 22u | GRM31CR61A226KE19L | Capacitor_SMD__C_1206_3216Metric | False
C43 | 100n | GRM188R71H104KA93D | Capacitor_SMD__C_0603_1608Metric | False
U41 | SN74LVC8T245PWR | SN74LVC8T245PWR | Package_SO__TSSOP-24_4.4x7.8mm_P0.65mm | False
U42 | SN74LVC8T245PWR | SN74LVC8T245PWR | Package_SO__TSSOP-24_4.4x7.8mm_P0.65mm | False
C44 | 100n | GRM188R71H104KA93D | Capacitor_SMD__C_0603_1608Metric | False
C45 | 100n | GRM188R71H104KA93D | Capacitor_SMD__C_0603_1608Metric | False
C46 | 100n | GRM188R71H104KA93D | Capacitor_SMD__C_0603_1608Metric | False
C47 | 100n | GRM188R71H104KA93D | Capacitor_SMD__C_0603_1608Metric | False
R50 | 10k | RC0603FR-0710KL | Resistor_SMD__R_0603_1608Metric | False
R51 | 100k | RC0603FR-07100KL | Resistor_SMD__R_0603_1608Metric | False
U43 | ISO1640BDR | ISO1640BDR | Package_SO__SOIC-8_3.9x4.9mm_P1.27mm | False | Power-domain isolation only: grounds are joined. Side-1 VOL max 0.71V requires host VIL >=0.8V; verify Pi revision.
C48 | 100n | GRM188R71H104KA93D | Capacitor_SMD__C_0603_1608Metric | False
C49 | 100n | GRM188R71H104KA93D | Capacitor_SMD__C_0603_1608Metric | False
R52 | 4.7k | RC0603FR-074K7L | Resistor_SMD__R_0603_1608Metric | False
R53 | 4.7k | RC0603FR-074K7L | Resistor_SMD__R_0603_1608Metric | False
TP1 | SENS_3V3 | SENS_3V3 | TestPoint__TestPoint_Pad_D1.5mm | False
TP2 | GND | GND | TestPoint__TestPoint_Pad_D1.5mm | False
TP4 | SENSOR_OE_N | SENSOR_OE_N | TestPoint__TestPoint_Pad_D1.5mm | False
U51 | TXU0202DCUR | TXU0202DCUR | Package_SO__VSSOP-8_2.3x2mm_P0.5mm | False
C75 | 100n | GRM188R71H104KA93D | Capacitor_SMD__C_0603_1608Metric | False
C76 | 100n | GRM188R71H104KA93D | Capacitor_SMD__C_0603_1608Metric | False
R61 | 47 | RC0603FR-0747RL | Resistor_SMD__R_0603_1608Metric | False
R62 | 100k | RC0603FR-07100KL | Resistor_SMD__R_0603_1608Metric | False
R63 | 10k | RC0603FR-0710KL | Resistor_SMD__R_0603_1608Metric | False
U52 | TLV803EA30DBZR | TLV803EA30DBZR | Package_TO_SOT_SMD__SOT-23 | False | 3.0V falling threshold, 200ms nominal release delay; open-drain output.
C77 | 100n | GRM188R71H104KA93D | Capacitor_SMD__C_0603_1608Metric | False
R64 | 10k | RC0603FR-0710KL | Resistor_SMD__R_0603_1608Metric | False
Q1 | 2N7002 | 2N7002 | Package_TO_SOT_SMD__SOT-23 | False | Pi GPIO17 HIGH asserts chip reset; does not drive a live voltage into unpowered chip.
R65 | 1k | RC0603FR-071KL | Resistor_SMD__R_0603_1608Metric | False
R66 | 100k | RC0603FR-07100KL | Resistor_SMD__R_0603_1608Metric | False
J80 | LSHM-150-04.0-L-DV-A-S-K-TR | LSHM-150-04.0-L-DV-A-S-K-TR | TZ_TZ100 | False | Mates JM1; opposite parity; 8 mm board surface gap
J81 | LSHM-150-04.0-L-DV-A-S-K-TR | LSHM-150-04.0-L-DV-A-S-K-TR | TZ_TZ100 | False | Mates JM2; opposite parity; 8 mm board surface gap
J82 | LSHM-130-04.0-L-DV-A-S-K-TR | LSHM-130-04.0-L-DV-A-S-K-TR | TZ_TZ60 | False | Mates JM3; opposite parity; 8 mm board surface gap
J83 | 1715721 | 1715721 | TZ_TZ_POWER | False | REGULATED 3.3 V ONLY; external current-limited supply; 3 A initial operating budget Shifted left to keep power-terminal tails out of the J86 ribbon corridor.
F80 | 0467005.NR | 0467005.NR | TZ_TZ_FUSE | False | 5 A fast fuse; not reverse-polarity or overvoltage protection
JP80 | TSW-102-07-G-S | TSW-102-07-G-S | TZ_TZ_JP | False | Fit shunt to DISABLE module; open enables on-board sequence
JP81 | TSW-102-07-G-S | TSW-102-07-G-S | TZ_TZ_JP | False | Fit shunt to request module configuration reset
R80 | 10k | RC0603FR-0710KL | Resistor_SMD__R_0603_1608Metric | False | FPGA JTAG selection / spare CPLD control idle pull-down
R81 | 10k | RC0603FR-0710KL | Resistor_SMD__R_0603_1608Metric | False | FPGA JTAG selection / spare CPLD control idle pull-down
C80 | 22u | GRM31CR61A226KE19L | Capacitor_SMD__C_1206_3216Metric | False | Carrier local decoupling; module contains core decoupling
C81 | 22u | GRM31CR61A226KE19L | Capacitor_SMD__C_1206_3216Metric | False | Carrier local decoupling; module contains core decoupling
C82 | 22u | GRM31CR61A226KE19L | Capacitor_SMD__C_1206_3216Metric | False | Carrier local decoupling; module contains core decoupling
C83 | 100n | GRM188R71H104KA93D | Capacitor_SMD__C_0603_1608Metric | False | Carrier local decoupling; module contains core decoupling
C84 | 4.7u | GRM21BR71A475KA73L | Capacitor_SMD__C_0805_2012Metric | False | Carrier local decoupling; module contains core decoupling
C85 | 4.7u | GRM21BR71A475KA73L | Capacitor_SMD__C_0805_2012Metric | False | Carrier local decoupling; module contains core decoupling
H80 | M3 / 8 mm spacer | M3 / 8 mm spacer | TZ_TZ_HOLE | False
H81 | M3 / 8 mm spacer | M3 / 8 mm spacer | TZ_TZ_HOLE | False
H82 | M3 / 8 mm spacer | M3 / 8 mm spacer | TZ_TZ_HOLE | False
H83 | M3 / 8 mm spacer | M3 / 8 mm spacer | TZ_TZ_HOLE | False
U22 | ADS122C04 | ADS122C04IPWR | Package_SO__TSSOP-16_4.4x5mm_P0.65mm | False | I2C 0x40; internal 2.048V reference, gain 64, normal 330 SPS; unused analog/reference inputs open per TI.
J90 | GEO + / - / SHIELD | 1803439 | Connector_Phoenix_MC__PhoenixContact_MCV_1,5_3-G-3.81_1x03_P3.81mm_Vertical | False | External passive sensor: 1 positive, 2 negative, 3 cable shield. Mate MC 1,5/3-ST-3,81. Never connect power.
D90 | TPD2E2U06 | TPD2E2U06DCKR | Package_TO_SOT_SMD__SOT-323_SC-70 | False | Connector ESD suppression only; not lightning protection.
R90 | 1k | RC0603FR-071KL | Resistor_SMD__R_0603_1608Metric | False | Matched series input filter / current limiting.
R91 | 1k | RC0603FR-071KL | Resistor_SMD__R_0603_1608Metric | False
C90 | 100n C0G | C3216C0G1H104J160AA | Capacitor_SMD__C_1206_3216Metric | False | C0G differential filter; no piezoelectric X7R on signal path.
C91 | 1n C0G | C0603C102J5GACTU | Capacitor_SMD__C_0603_1608Metric | False
C92 | 1n C0G | C0603C102J5GACTU | Capacitor_SMD__C_0603_1608Metric | False
R92 | 1M | RC0603FR-071ML | Resistor_SMD__R_0603_1608Metric | False
R93 | 1M | RC0603FR-071ML | Resistor_SMD__R_0603_1608Metric | False
R94 | 10k | RC0603FR-0710KL | Resistor_SMD__R_0603_1608Metric | False
R95 | 10k | RC0603FR-0710KL | Resistor_SMD__R_0603_1608Metric | False
C93 | 10u | GRM21BR61A106KE19L | Capacitor_SMD__C_0805_2012Metric | False | Filtered mid-supply; sensor has no excitation current source.
R96 | 22 | RC0603FR-0722RL | Resistor_SMD__R_0603_1608Metric | False
C94 | 10u | GRM21BR61A106KE19L | Capacitor_SMD__C_0805_2012Metric | False
C95 | 100n | GRM188R71H104KA93D | Capacitor_SMD__C_0603_1608Metric | False
C96 | 100n | GRM188R71H104KA93D | Capacitor_SMD__C_0603_1608Metric | False
R97 | 10k | RC0603FR-0710KL | Resistor_SMD__R_0603_1608Metric | False | Open-drain DRDY pullup; existing U42 return buffer to BCM4.
U100 | TMUX1574PWR | TMUX1574PWR | Package_SO__TSSOP-16_4.4x5mm_P0.65mm | False | SEL=0 application, SEL=1 native JTAG; EN high isolates; FPGA-powered with power-off protection.
U101 | TMUX1574PWR | TMUX1574PWR | Package_SO__TSSOP-16_4.4x5mm_P0.65mm | False | S1B/S2B deliberately open parking paths: isolate CS/DQ3 in JTAG. Unused complete channels grounded.
U102 | TCA9534PWR | TCA9534PWR | Package_SO__TSSOP-16_4.4x5mm_P0.65mm | False | I2C 0x20. Write output 0 before config 0xFC. P2-P7 remain grounded inputs; INT unused. Pi header supplies I2C pullups.
U103 | SN74LVC1G10DCKR | SN74LVC1G10DCKR | Package_TO_SOT_SMD__SOT-363_SC-70-6 | False | Disable unless request AND both independent rail supervisors are high; inputs tolerate an unpowered gate.
U104 | TLV809EA30DBZR | TLV809EA30DBZR | Package_TO_SOT_SMD__SOT-23 | False | 3.0 V threshold, 200 ms nominal release, push-pull. Separate from application reset.
U105 | TLV809EA30DBZR | TLV809EA30DBZR | Package_TO_SOT_SMD__SOT-23 | False | 3.0 V threshold, 200 ms nominal release, push-pull. Separate from application reset.
C100 | 100n | GRM188R71H104KA93D | Capacitor_SMD__C_0603_1608Metric | False
C101 | 100n | GRM188R71H104KA93D | Capacitor_SMD__C_0603_1608Metric | False
C102 | 100n | GRM188R71H104KA93D | Capacitor_SMD__C_0603_1608Metric | False
C103 | 100n | GRM188R71H104KA93D | Capacitor_SMD__C_0603_1608Metric | False
C104 | 100n | GRM188R71H104KA93D | Capacitor_SMD__C_0603_1608Metric | False
C105 | 100n | GRM188R71H104KA93D | Capacitor_SMD__C_0603_1608Metric | False
R100 | 22 | RC0603FR-0722RL | Resistor_SMD__R_0603_1608Metric | False | 22 ohm series damping; quad data paths are bidirectional. Qualify maximum clock on hardware.
R101 | 22 | RC0603FR-0722RL | Resistor_SMD__R_0603_1608Metric | False | 22 ohm series damping; quad data paths are bidirectional. Qualify maximum clock on hardware.
R102 | 22 | RC0603FR-0722RL | Resistor_SMD__R_0603_1608Metric | False | 22 ohm series damping; quad data paths are bidirectional. Qualify maximum clock on hardware.
R103 | 22 | RC0603FR-0722RL | Resistor_SMD__R_0603_1608Metric | False | 22 ohm series damping; quad data paths are bidirectional. Qualify maximum clock on hardware.
R104 | 22 | RC0603FR-0722RL | Resistor_SMD__R_0603_1608Metric | False | 22 ohm series damping; quad data paths are bidirectional. Qualify maximum clock on hardware.
R105 | 22 | RC0603FR-0722RL | Resistor_SMD__R_0603_1608Metric | False | 22 ohm series damping; quad data paths are bidirectional. Qualify maximum clock on hardware.
R106 | 10k | RC0603FR-0710KL | Resistor_SMD__R_0603_1608Metric | False
R107 | 10k | RC0603FR-0710KL | Resistor_SMD__R_0603_1608Metric | False
R108 | 10k | RC0603FR-0710KL | Resistor_SMD__R_0603_1608Metric | False
R109 | 10k | RC0603FR-0710KL | Resistor_SMD__R_0603_1608Metric | False
R110 | 10k | RC0603FR-0710KL | Resistor_SMD__R_0603_1608Metric | False
R111 | 10k | RC0603FR-0710KL | Resistor_SMD__R_0603_1608Metric | False
R112 | 100k | RC0603FR-07100KL | Resistor_SMD__R_0603_1608Metric | False
R113 | 10k | RC0603FR-0710KL | Resistor_SMD__R_0603_1608Metric | False
R114 | 100k | RC0603FR-07100KL | Resistor_SMD__R_0603_1608Metric | False
R115 | 10k | RC0603FR-0710KL | Resistor_SMD__R_0603_1608Metric | False
R116 | 100k | RC0603FR-07100KL | Resistor_SMD__R_0603_1608Metric | False
R117 | 100k | RC0603FR-07100KL | Resistor_SMD__R_0603_1608Metric | False
U106 | SN74LVC1G08DCKR | SN74LVC1G08DCKR | Package_TO_SOT_SMD__SOT-353_SC-70-5 | False | Existing BCM25 FPGA_IO_ENABLE is also a hardware disarm independent of I2C. Default-low R62 retained.
C106 | 100n | GRM188R71H104KA93D | Capacitor_SMD__C_0603_1608Metric | False

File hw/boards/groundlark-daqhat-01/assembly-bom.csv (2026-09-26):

Item | Quantity | Part | Note
Carrier assembly | 1 | Groundlark DAQHAT-01 | Use generated bom.csv for carrier electronic components
FPGA module | 1 | TE0712-03-81I36-A | XC7A200T-1FBG484I; standard 4 mm connectors
Trenz spacers | 4 | M3 8 mm surface-gap spacers | Match actual mating stack; insulated hardware preferred near copper
Trenz fasteners | 4 | M3 screws | Select length for actual spacers; avoid bottoming
Pi GPIO riser | 1 | Samtec SSQ-120-02-G-D | Unmounted 2x20 socket; 8.51 mm body; 4.93 mm square gold-flash tails into J1; female face toward Pi; verify full insertion and 1:1 pin numbering
Pi spacers | 4 | Approximately 27.18 mm effective clearance | Select measured spacers/shims for ESQ-120-23-G-D plus SSQ riser and Pi header mating
Pi fasteners | 4 | M2.5 screws | Select length for actual spacers
Host | 1 | Raspberry Pi 4 Model B | Selected bench host; Pi 5 not covered by this fit review
Module power | 1 | Adjustable regulated current-limited supply | 3.35 V +/-0.5% at J83; maintain 3.201-3.399 V at module; total hot supply-and-ground path <=30 milliohms for 3 A operating budget
Cooling | 1 | Workload-dependent FPGA heatsink | Select after power/thermal testing; not included in nominal height model
Geophone cable plug | 1 | Phoenix Contact 1803581 | MC 1.5/3-ST-3.81; mates J90; route cable south and keep service column clear; see docs/stack-assembly.md
External geophone | 1 | Racotech RGI-4.5Hz vertical | 395 ohm; 23.4 V/(m/s); separate vertical ground-coupled mount
Pi heatsink | 1 | 18 x 18 x 10 mm heatsink from Raspberry Pi 4 Case Fan kit | Heatsink only; 0.5 mm adhesive envelope; fan absent; thermal performance pending

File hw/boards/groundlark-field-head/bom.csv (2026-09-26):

Reference | Value | MPN | Footprint | DNP | Note
J1 | USB-C DEVICE | USB4105-GF-A | Connector_USB__USB_C_Receptacle_GCT_USB4105-xx-A_16P_TopMnt_Horizontal | False
R1 | 5.1k | RC0603FR-075K1L | Resistor_SMD__R_0603_1608Metric | False
R2 | 5.1k | RC0603FR-075K1L | Resistor_SMD__R_0603_1608Metric | False
D1 | USBLC6-2SC6 | USBLC6-2SC6 | Package_TO_SOT_SMD__SOT-23-6 | False
D2 | USBLC6-2SC6 | USBLC6-2SC6 | Package_TO_SOT_SMD__SOT-23-6 | False
F1 | 500mA PTC | MF-MSMF050-2 | Fuse__Fuse_1812_4532Metric | False
U4 | AP2112K-3.3 | AP2112K-3.3TRG1 | Package_TO_SOT_SMD__SOT-23-5 | False
C1 | 2.2u | GRM21BR71E225KA73L | Capacitor_SMD__C_0805_2012Metric | False
C2 | 4.7u | GRM21BR71A475KA73L | Capacitor_SMD__C_0805_2012Metric | False
U1 | STM32F042K6T6 | STM32F042K6T6 | Package_QFP__LQFP-32_7x7mm_P0.8mm | False
C3 | 100n | GRM188R71H104KA93D | Capacitor_SMD__C_0603_1608Metric | False
C6 | 100n | GRM188R71H104KA93D | Capacitor_SMD__C_0603_1608Metric | False
C7 | 100n | GRM188R71H104KA93D | Capacitor_SMD__C_0603_1608Metric | False
C8 | 100n | GRM188R71H104KA93D | Capacitor_SMD__C_0603_1608Metric | False
R3 | 10k | RC0603FR-0710KL | Resistor_SMD__R_0603_1608Metric | False
R4 | 10k | RC0603FR-0710KL | Resistor_SMD__R_0603_1608Metric | False
J2 | SWD / 3V3 SENSE | M20-9990545 | Connector_PinHeader_2.54mm__PinHeader_1x05_P2.54mm_Vertical | False | Pin 1 is target voltage sense; do not externally power the rail
J3 | BOOT0 jumper | EEPROM write enable | Connector_PinHeader_2.54mm__PinHeader_1x02_P2.54mm_Vertical | False
U5 | TPS22919 | TPS22919DCKR | Package_TO_SOT_SMD__SOT-363_SC-70-6 | False
R5 | 100k | RC0603FR-07100KL | Resistor_SMD__R_0603_1608Metric | False
C9 | 100n | GRM188R71H104KA93D | Capacitor_SMD__C_0603_1608Metric | False
R7 | 4.7k | RC0603FR-074K7L | Resistor_SMD__R_0603_1608Metric | False
R8 | 4.7k | RC0603FR-074K7L | Resistor_SMD__R_0603_1608Metric | False
U2 | RM3100 XYZ | PNI 14190 | Groundlark__PNI_14190_Module | False
C4 | 100n | GRM188R71H104KA93D | Capacitor_SMD__C_0603_1608Metric | False
U3 | DLVR-F50D option | DLVR-F50D-E1BS-I-NI3F | Groundlark__DLVR_E1BS | True
C5 | 100n | GRM188R71H104KA93D | Capacitor_SMD__C_0603_1608Metric | False
H1 | M2.5 NPTH | M2.5 NPTH | MountingHole__MountingHole_2.7mm_M2.5 | False
H2 | M2.5 NPTH | M2.5 NPTH | MountingHole__MountingHole_2.7mm_M2.5 | False
H3 | M2.5 NPTH | M2.5 NPTH | MountingHole__MountingHole_2.7mm_M2.5 | False
H4 | M2.5 NPTH | M2.5 NPTH | MountingHole__MountingHole_2.7mm_M2.5 | False

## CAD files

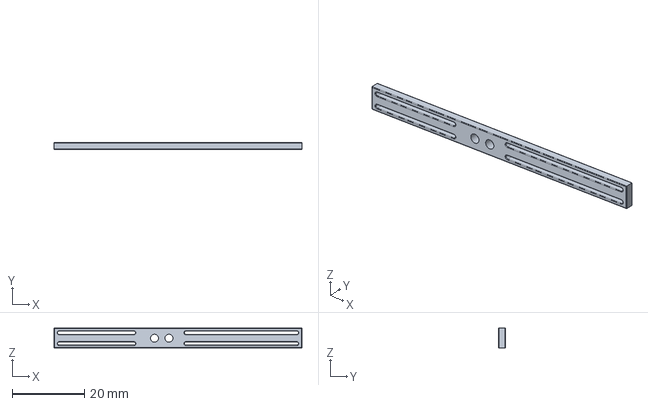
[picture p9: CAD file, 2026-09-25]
hw/mechanical/daqhat-01-ribbon-guide/ribbon-guide.step
68.5 x 2.00 x 5.50 mm

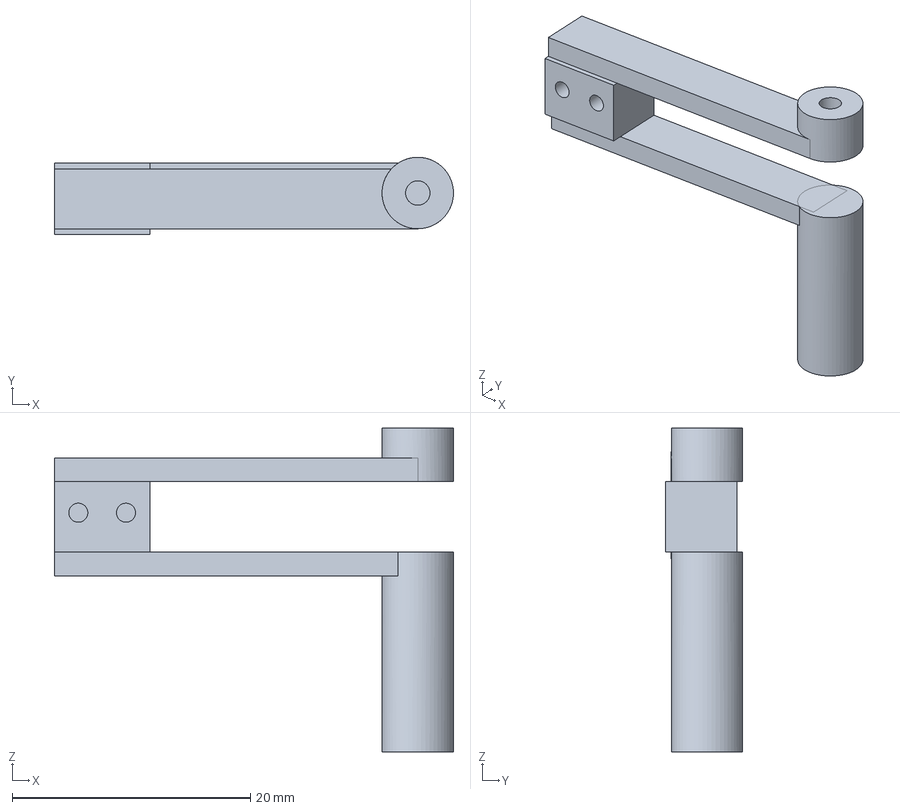
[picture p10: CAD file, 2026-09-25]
hw/models/DAQHAT_01_offset-spacer.step
33.5 x 6.50 x 27.2 mm

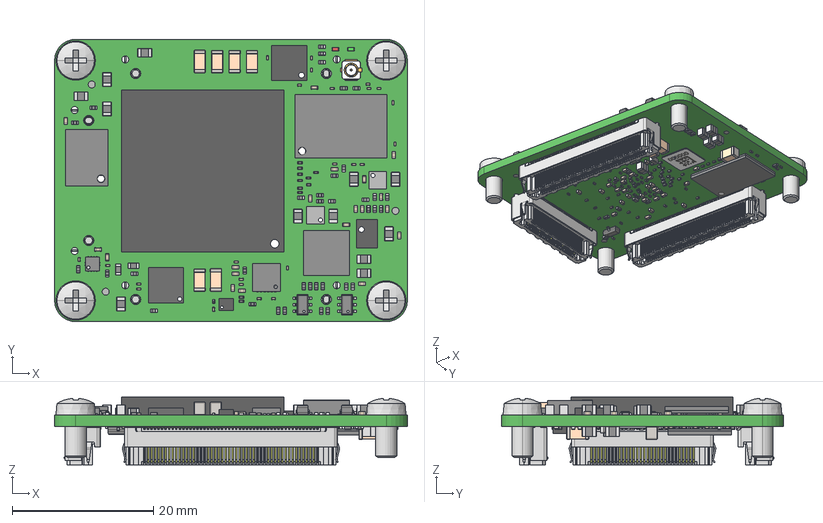
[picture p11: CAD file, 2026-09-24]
hw/models/trenz/STP-TE0712-03-No Variations.step
50.0 x 40.0 x 9.61 mm
RES_0603-0201 x 28
User Library-SMD CAPACITOR0402 x 51
User Library-SMD 0201 CAPACITOR x 92
Extruded x 8
User Library-CAPC3216X___CAPC3216X180N x 9
ASMPH-0603 x 2
User Library-QFN24-0_5_Fusion
User Library-QFN24-0_5_QFN24_0_5024
User Library-QFN24-0_5_Cut
_STRLSHM-30-04.0-DV-A-S
_C-185--30-04.0-DV1P
_STRLSHM-50-04.0-DV-A-S x 2
_C-185--50-04.0-DV1P x 2
622173x6 x 4
led_0402LED0402 green
led_0402-red
SW3dPS-U.FL-R-SMT-1
Label

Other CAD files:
hw/mechanical/daqhat-01-ribbon-guide/offset-spacer.step
hw/models/DAQHAT_01_ribbon-guide.step
hw/mechanical/daqhat-01-ribbon-guide/offset-spacer.stl
hw/mechanical/daqhat-01-ribbon-guide/ribbon-guide.stl

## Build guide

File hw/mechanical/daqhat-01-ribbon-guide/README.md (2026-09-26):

# Retired mechanical design

This guide and offset spacer belong to revision `64d4190`. DAQHAT-01 removes
the external connectors and uses four straight supports. These archived assets
are not part of the current assembly or fabrication package.

# DAQHAT-01 ribbon spacer and guide

This assembly replaces the **south-right straight Pi spacer** when fitting
J86-J89. It preserves all four Pi mounting points and the 85 x 56 mm PCB.
The guide projects 2 mm past the south board edge; the flexible tails continue
outward. It does not change the Pi/HAT or HAT/Trenz stack heights.

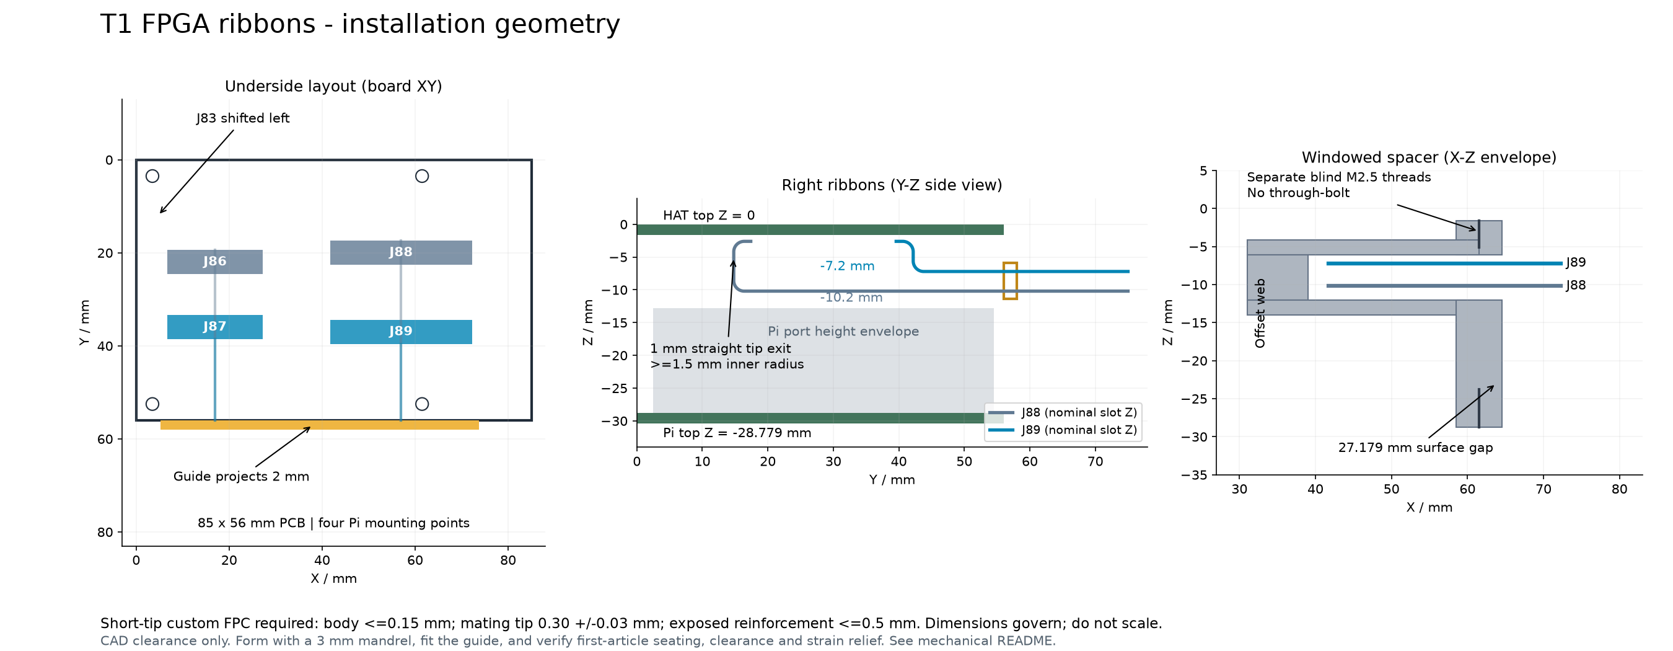
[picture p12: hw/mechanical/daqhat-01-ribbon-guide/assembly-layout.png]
Dimensioned installation geometry


Files: `offset-spacer.step` is the machined structural part;
`ribbon-guide.step` and `.stl` are the insulating guide. The spacer STL is
for visualization/mock-up, not a substitution of printed plastic for aluminum.
STEP coordinates use the HAT top-left, top surface Z=0, +Y south, units mm.
The separately generated display STEP copies in `hw/models` have Y reversed
for KiCad. Bores in STEP are tap-drill sizes, not modeled screw threads.

## Manufacturing dimensions

- Spacer material: machined 6061-T6 aluminum, deburred. Insulate its upper arm
  with thin polyimide film; finished top envelope must remain Z <= -4.0 mm.
- Boss centers: X=61.5, Y=52.5; diameter 6.0 mm. Overall support height
  27.179 mm (HAT underside Z=-1.6 to Pi top Z=-28.779). Adjust only with
  measured shims to match fully seated Pi sockets; do not preload/bow PCBs.
- Top boss reaches Z=-6.1. Upper arm: X=31..61.5, Y=50.5..55.5,
  Z=-6.1..-4.1 (2 mm thick). Offset web: X=31..39, Y=50..56,
  Z=-12..-6.1. Lower arm: X=31..61.5, Y=50..55, Z=-14..-12.
- Top M2.5 x 0.45 blind thread: at least 2.5 mm full thread, 3.5 mm drill
  depth. Bottom M2.5 x 0.45: at least 4 mm full thread, 5 mm drill depth.
  **Separate short screws; never a through-bolt across the cable window.**
  Select screw lengths for 2.0..2.5 mm engagement at the top and 3..4 mm at
  the bottom, after PCB/washer thickness. Verify they cannot bottom out.
- Two M2 x 0.4 blind guide threads from the south web face Y=56: X=33 and
  X=37, Z=-8.7; 3 mm full thread, 4 mm tap drill depth. Guide mounting holes
  are 2.2 mm clearance; use M2 x 5 mm screws with <=3.8 mm diameter heads.
- Guide: insulating PA12 or machined POM. X=5.25..73.75, Y=56..58,
  Z=-11.4..-5.9. Four 0.9 mm high slots, centers X=17/57 and
  Z=-7.2/-10.2; widths 21.5/31.5 mm respectively. Entrance radii 0.15 mm
  are in the STEP. Smooth and inspect slots; no rough print ridges on flex.
- General machining tolerance +/-0.10 mm; guide slots +/-0.10 mm, clear of
  burrs. Verify final stack before tightening. CAD clearance includes 0.5 mm
  cable-placement allowance and 1 mm allowance above Pi port envelopes.

## Cable contract

Use **custom single-layer polyimide FPC tails**, nominal length 150 mm,
0.50 mm contact pitch, 20.5 mm (40 contacts) / 30.5 mm (60 contacts) width.
The flexible body including coverlay must be <=0.15 mm. No vias, splices,
stiffeners or copper planes in the bending regions. Use bend-to-install
construction, not a continuously moving harness.

The connector tips must match Amphenol F32Q's supplier drawing, including
0.30 +/-0.03 mm total mating thickness. The stiffener must end **at most
0.5 mm beyond the latched connector mouth**. Allow 1 mm of straight exit
before each 1.5 mm radius bend. Set reinforcement length from actual insertion
depth; do not assume a generic FFC's 5-10 mm reinforcement is compatible.
The far-end contact orientation and mapping must match its eventual receiver.
This is a mechanical procurement contract, not a released receiver harness
or a claim that an off-the-shelf cable has been qualified.

The 1.5 mm minimum inner radius is 10 times the maximum flex-body thickness.
The model uses 1.6 mm centreline radii, leaving at least 1.5 mm on the inside
of the specified 0.15 mm body. This exceeds
the single-layer 6x static guidance in [JLCPCB's flex capabilities](https://jlcpcb.com/capabilities/flex-pcb-capabilities)
and follows the conservative 10x approach discussed in [Minco's design guide](https://www.minco.com/wp-content/uploads/Minco-Flex-Circuits-Design-Guide-2019.pdf).
Obtain the cable maker's stackup/bend confirmation; those general rules do not
qualify a particular material stack or repeated flexing.

## Installation

1. Trim and inspect all underside through-hole ends: <=2 mm below the HAT,
   including solder. Check the guide and spacer for burrs and dimensions.
2. Pass all four tails through the guide before inserting their connector
   tips. J86/J88 use the lower slots; J87/J89 use the upper slots.
3. Form bends over a smooth 3 mm diameter mandrel while supporting the free
   cable, before final insertion. Maintain >=1.5 mm radius, the 1 mm straight
   exits and a vertical tangent between each pair of quarter-circle bends.
   Do not pull on the latch or crease the flex to achieve the final position.
4. Seat/latch tips with contact side away from the underside PCB, then check
   the unbent reinforced portion ends before the first bend. Fit the guide
   and windowed spacer, then lower the assembly onto the Pi riser.
5. Check at least 0.25 mm clearance to J83's tails, separation between ribbons,
   free travel through slots and >=1 mm space above the Pi ports. Add strain
   relief outside the stack; the guide is a locator, not a cable pull clamp.
6. Inspect under load, mate-cycle and temperature during first-article work.
   The CAD checks are not a measurement of stiffness, pull strength or fatigue.

Generate mechanical CAD with Python 3.12 + `cadquery-ocp==8.0.1.0.0`:
`python hw/tools/ribbon_mechanics.py`. This optional tool does not alter the
PCB and is kept out of the portable electronics test environment. Geometry
and regressions run through the normal lab without that dependency.

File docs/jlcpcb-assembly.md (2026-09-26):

# JLCPCB assembled DAQHAT-01 HAT

The package targets **one fabricated PCB and one assembled HAT**, the same
physical board. The HAT is 85 × 56 mm with 117 placements and 38 BOM lines.
The Pi, Trenz module, geophone, riser, supply and mounting hardware are separate
purchases. The remote sensor head and A2 ASIC HAT are not included.

## Files to upload

| File | Local package |
| --- | --- |
| `DAQHAT-01-Gerbers-REVIEW.zip` | `hw/releases/groundlark-daqhat-01-jlcpcb-review-20260926-one-hat/` |
| `BOM-review.csv` and `CPL-review.csv` together | `hw/releases/groundlark-daqhat-01-jlcpcb-placement-20260926-c91-c92/` |

Use the BOM and CPL from the same overlay. Do not reuse the base package's BOM/CPL
or previous manual rotation overrides. Gerbers contain one closed outline;
BOM quantities are per HAT. Set the supplier's PCB and assembly quantities
separately: the CSV cannot control the website's quantity selector.

Packages remain local and Git-ignored. They include checksums and validation
records; source CAD, part, side or process changes require a fresh export.
The package retains manufacturing holds and is not a fabrication approval.

## Fabrication and assembly requirements

- Six-layer FR-4, nominal 1.6 mm, TG135, ENIG, 1 oz outer / 0.5 oz inner copper.
  Use the stock JLC06161H-3313 stack, with no HDI or custom lamination.
  Its 1.5384 mm copper/dielectric sum is ordered as nominal 1.6 mm, ±10%.
- Through-vias only, 0.30 mm drill, epoxy-filled and copper-capped (POFV),
  including vias in solder pads. Tenting alone is insufficient.
  Do not fill component plated holes or non-plated mounting holes.
- Double-sided assembly: 107 SMT-only placements, seven THT-only placements and
  three mixed SMT/THT connectors. J80/J81/J82 have SMT contacts and plated mounts.
  J1 is the bottom Pi socket.
- Confirm the supplier's one-piece assembly acceptance, handling frame,
  fiducials, part allocation and process requirements. Recorded Standard PCBA
  rules require a two-piece minimum and a 70 mm minimum dimension; the 85 × 56 mm
  HAT therefore needs a supplier-agreed quantity exception and handling frame.
  Do not change the requested quantity without the owner's agreement.
- Verify the supplier placement preview and final proposed production data.
  CAD, modeled tests and catalog pad fits do not establish physical fit or DFM approval.

## BOM mapping and selected parts

The [exact-part registry](../hw/assembly/daqhat-01-jlcpcb-parts.json) binds each
reference to its source value/footprint and approved manufacturer, MPN and C-code.
Catalog listing does not reserve stock or guarantee assembly eligibility.
Recheck allocation at ordering; do not accept automatic substitutes.

| Upload field | CSV column |
| --- | --- |
| Comment / manufacturer part number | `Comment` (full orderable MPN) |
| Designator | `Designator` |
| Footprint / package | `Footprint` |
| JLCPCB / LCSC part number | `JLCPCB Part #` |

Do not use `Description` as the ordering code. Confirm all 38 nonblank catalog
identities and all 117 placements survive import.

| References | Assembly selection | Required specification |
| --- | --- | --- |
| J1 | Megastar ZX-PM2.54-2-20PY / C7499354 | Bottom-mounted 2×20 female socket, 8.5 mm body; stack fit remains open. |
| C42, C80–C82 | Samsung CL31A226KAHNNNE / C12891 | 22 µF, ±10%, X5R, 25 V, 1206. |
| C84, C85 | Murata GRM21BR71C475KE51L / C408144 | 4.7 µF, ±10%, X7R, 16 V, 0805. |
| C90 | Murata GRM31C5C1H104JA01L / C97946 | 100 nF, ±5%, C0G, 50 V, 1206. |
| C91, C92 | KEMET C0603C102J5GAC7867 / C140950 | 1 nF, ±5%, C0G, 50 V, 0603. |
| F80 | Littelfuse 0466005.NRHF / C57525 | 5 A fast fuse, 32 V, 1206. |

F80 must use the 1206 assembly selection; the 0603 source-schematic MPN is not
an approved assembly part. Its nominal cold resistance is 11 mΩ, which is
included in the **30 mΩ total hot power-loop budget**, not an allowance in
addition to it. Check hot voltage drop, startup and fuse behavior on hardware.
Signal capacitors C90–C92 must retain C0G dielectric, tolerance and voltage rating.

**J1 fit remains unresolved:** its 8.5 mm body is shorter than the Samtec socket
in the baseline CAD and stack render. Riser/spacer height, pin engagement and
bottom-side orientation need confirmation. The previous tall-socket geometry
does not qualify this part. See [stack assembly](stack-assembly.md).

## Placement conventions

The exporter fits supplier numbered pads to native footprints using the frozen
[catalog geometry](../hw/assembly/daqhat-01-jlcpcb-placement.json). It accounts
for bottom-side projection and preserves absolute component positions.
Use its CPL rather than raw KiCad angles or manual per-reference offsets.

| References | Supplier CPL rotation |
| --- | --- |
| J1 (Bottom) | 0° |
| J4 | 270° |
| JP1, JP80, JP81 | 0° |
| J80, J81 | 180° |
| J82, J83 | 270° |
| J90 | 180° |
| U1, U22, U41, U42 | 270° |
| U100–U103 (Bottom) | 270° |
| Q1, U40, U51, U52 | 180° |
| D90 (Bottom), C91, C92 (Top) | 0° |

Check J1's underside model and pin-1 direction in the supplier preview. Its
front-layer land pattern requires a bottom-mounted socket. Confirm mixed
SMT/THT assembly, reflow/cleaning limits and sensor handling with the supplier.
Each placement must have a part-bound catalog mapping
or explicit exception. Changed MPNs or footprints invalidate those mappings.
The full exporter and overlay use the same solver; repeated export does not
apply an extra rotation. This checks registration, not solder-joint reliability.

## Reproduce exports without changing CAD

Use KiCad 9.0.9 and a Python that imports `pcbnew` (WSL or the portable lab).
The exporter rejects source CAD/BOM hashes that differ from recorded validation,
checks all native DRC severities, validates the layer/drill inventory, and verifies
that BOM and CPL references agree. It refuses to overwrite a populated directory.

```bash
python3 hw/tools/jlcpcb_package.py --quantity 1 --output .local/jlcpcb/new-review
python3 -m unittest discover -s hw/tests -p 'test_jlcpcb*.py' -v
```

For optional independent plot inspection and PDF production, keep dependencies
inside the repo rather than installing into the atopile environment. The review
renderer uses rsvg-convert for luminance masks so silkscreen cutouts preserve
underlying copper, and draws the silkscreen above copper:

```bash

# Also requires rsvg-convert (librsvg2-bin on Debian/Ubuntu).
python3 -m venv --system-site-packages .local/fab-venv
.local/fab-venv/bin/pip install gerbonara==1.5.0 reportlab==4.4.10
.local/fab-venv/bin/python hw/tools/jlcpcb_inspect.py .local/jlcpcb/new-review
.local/fab-venv/bin/python hw/tools/jlcpcb_drawings.py .local/jlcpcb/new-review
```

The independent parser compares every exported hole location, diameter and
span to CAD (1 micrometre coordinate quantization), and parses all 13 plot layers.
The package report gives actual drill counts; no blind-drill files are accepted.
It emits benign parser warnings about KiCad's G90 header position and unused
RoundRect macro parameters; these are retained rather than suppressed. Render
the PDF with `pdftoppm` and inspect each page. Gerber parsing does not establish
DFM approval or validate solder-paste apertures against supplier process limits.

After adding the package README and reviewing the PDF, run
`python3 hw/tools/jlcpcb_seal.py .local/jlcpcb/new-review` to write checksums
and the complete review ZIP. This retains all manufacturing holds; it does not
promote the package to an approved release.

## Sources reviewed 2026-09-25

- [JLCPCB assembly capabilities](https://jlcpcb.com/capabilities/pcb-assembly-capabilities):
  Standard service, two-piece minimum, panel dimensions, rails and fiducials.
- [PCB capabilities](https://jlcpcb.com/capabilities/Capab) and
  [six-layer POFV](https://jlcpcb.com/news/free-via-in-pad-6-20-layer-pcbs-pofv).
- [KiCad 9 export guide](https://jlcpcb.com/help/article/how-to-generate-gerber-and-drill-files-in-kicad-9).
- [BOM format](https://jlcpcb.com/help/article/bill-of-materials-for-pcb-assembly)
  and [CPL format](https://jlcpcb.com/help/article/pick-place-file-for-pcb-assembly).
- [Parts sourcing](https://jlcpcb.com/help/article/pcba-parts-sourcing-instruction).
- [LSM6DSOTR catalog](https://jlcpcb.com/partdetail/LSM6DSOTR/C2655100)
  and [TCA9534PWR catalog](https://jlcpcb.com/partdetail/TexasInstruments-TCA9534PWR/C783615).

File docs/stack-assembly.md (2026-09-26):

# DAQHAT-01 bench assembly

Bottom to top: Pi 4, 85 x 56 mm DAQHAT-01 sensor HAT, TE0712-03-81I36-A.
Four straight Pi supports replace the previous ribbon guide and offset spacer.
J84-J89 and all external FPGA ribbon cables are removed. Programming and data
travel through J1 and the Trenz mezzanine connectors; see the
[host-link guide](fpga-host-link.md).

## Selected hardware

| Item | Selection | Fit rule |
| --- | --- | --- |
| Host | Raspberry Pi 4 Model B | Pi 5/cooler not covered. |
| Pi cooling | Official Pi 4 Case Fan kit 18 x 18 x 10 mm heatsink | Allow 0.5 mm adhesive; fan omitted. |
| Pi riser | SSQ-120-02-G-D plus existing ESQ-120-23-G-D | 27.179 mm nominal Pi top to HAT underside. |
| Pi supports | Four straight M2.5 supports, <=4.8 mm outside diameter | Match seated riser/socket height with measured spacers/shims. |
| FPGA | TE0712-03-81I36-A with standard connectors | Four M3 spacers; 8 mm HAT-to-module surface gap. |
| Geophone plug | Phoenix Contact 1803581 | J90: GEO+, GEO-, shield/GND. |

The geophone plug has 9.20 mm calculated lateral clearance to the module after
0.5 mm allowance. Keep a vertical withdrawal column above J90, route its shielded
twisted pair toward the lower-left edge, and clamp the cable outside the PCB.
The geophone remains external, vertical and mechanically coupled to the ground.

**J1 procurement caveat:** the JLCPCB BOM selects the shorter 8.5 mm-body
Megastar ZX-PM2.54-2-20PY / C7499354. The 27.179 mm gap in the baseline table
does not apply automatically. Confirm mating depth, riser/spacer height and
cooler clearance for the ordered socket before assembly.

## Checks and limits

`assembly_fit.py` checks four support envelopes against the actual underside
components, socket, modeled Pi ports and selected heatsink. It reserves 0.5 mm
for support clearance and 1 mm for component/port seating uncertainty.
The [generated report](../hw/boards/groundlark-daqhat-01/prefab-review.json)
records margins. Use supports at (3.5,3.5), (61.5,3.5), (3.5,52.5), (61.5,52.5)
mm. Trim through-hole tails to <=2 mm below the HAT; the model allows 0.2 mm extra.

Keep the existing riser height. Removing cables does not qualify a shorter stack.
Actual mating, screws, cooler capacity, strain relief and sensor noise still need
a first-article check. The Pi and service envelopes are conceptual; the Trenz
model is the vendor's generic revision-03 STEP.

C95/C96 and D90 are underside geophone components; C90 is on the front.
ADC supply-pad and U101.4 link through-vias require epoxy-filled/copper-capped processing, as do the other
through-vias in this six-layer revision. Tenting alone does not meet this requirement.

See the [bench procedure](bench-procedure.md),
[Pi Case Fan brief](https://datasheets.raspberrypi.com/case-fan/case-fan-product-brief.pdf),
and [geophone plug](https://www.phoenixcontact.com/en-us/products/pcb-plug-mc-15-3-st-381-1803581).

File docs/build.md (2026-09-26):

# Reproducible A2 build

For validation in an isolated, portable environment, use the
[portable lab](portable-lab.md). It does not depend on the migrated local venvs.

The separate Pi-outline DAQHAT-01 build and rendering commands are in
[Trenz carrier documentation](trenz-hat.md#rebuild).

Used environment: WSL Ubuntu 24.04, atopile 0.15.9 with Python 3.14.7,
KiCad/pcbnew 9.0.9, ngspice 42 and Freerouting 1.9.0. These lower-level commands
require KiCad's system Python bindings, sexpdata, and ngspice in Linux/WSL.
Recreate an optional local atopile environment with an installed `uv`:

```sh
uv venv --python 3.14.7 .local/atopile
uv pip sync --python .local/atopile/bin/python --require-hashes environment/requirements.lock
```

Run the following from the repository root. They write authoring outputs; use
the portable lab for disposable validation instead. Freerouting's jar is a local
dependency at `hw/tools/freerouting-1.9.0.jar`, excluded from Git.

```sh
mkdir -p hw/logs
CI=1 .local/atopile/bin/python -m atopile build -v hw > hw/logs/atopile-build.log 2>&1
.local/atopile/bin/python hw/tools/solve_constraints.py > hw/logs/constraint-solve.log 2>&1
.local/atopile/bin/python hw/tools/solve_constraints.py --negative > hw/logs/negative-voltage.log 2>&1
python3 hw/tools/simulate.py
python3 hw/tools/assemble_pcb.py
```

`solve_constraints.py` explicitly invokes atopile's full numeric solver for
voltage/resistance/capacitance parameters. This is necessary because the stock
0.15.9 picker skips numeric solving for manually selected atomic components.
The negative case must reject 5 V applied to the 3.6 V IMU. No installed package
is patched and no electrical check is disabled. Component ratings use `assert
... within`; power sources specify their delivered range.

`assemble_pcb.py` resets routing, applies mechanical placement, adds the outline
and plane rules, and exports Specctra. It reads the compiled native KiCad board;
it does not create connections from a Python netlist. Save manual layout changes
before rerunning it. Electrical source is `hw/elec/*.ato`; `hw/layout.json` has no pin
net assignments. Review BOM presentation metadata when changing a selected MPN.

The checked route sessions are supplied with both boards. Reconstruct the
delivered layout after `assemble_pcb.py` with:

```sh
python3 hw/tools/import_routes.py
python3 hw/tools/trim_dangling.py
python3 hw/tools/widen_power.py
python3 hw/tools/review_schematic.py
python3 hw/tools/models.py
python3 hw/tools/check_circuit.py
python3 hw/tools/check_design.py
python3 hw/tools/report_validation.py
```

The HAT assembly step includes reviewed connector escapes and the short RF
trace; route sessions omit these fixed objects. Do not remove them before import.
The power-width pass tries 0.4/0.3/0.25/0.2 mm and uses native DRC to retain only
legal widening. Remaining 0.15 mm sections and per-net lengths are recorded in
`power-widths.json`; this is not an ampacity or extracted voltage-drop analysis.

For a changed placement/circuit, reroute each board and repeat the checks:

```sh
xvfb-run -a java -jar hw/tools/freerouting-1.9.0.jar \
  -de hw/boards/groundlark-hat/groundlark-hat.dsn \
  -do hw/boards/groundlark-hat/groundlark-hat.ses -mp 25 -mt 1 -da
# Repeat for groundlark-field-head.
python3 hw/tools/import_routes.py
python3 hw/tools/trim_dangling.py
python3 hw/tools/widen_power.py
python3 hw/tools/review_schematic.py
python3 hw/tools/models.py
python3 hw/tools/check_design.py
```

The restricted SES importer verifies placements and rejects unsupported route
objects. The HAT session retains the previous routing with an explicit allowlist of removed cable parts/nets; fixed geometry includes the replacement ground-plane via. KiCad performs independent DRC afterwards. Review schematics use local
symbols with physical pin numbers, explicit no-connects and documented supply
flags. They are derived artifacts, not a second electrical source.

Routing needed interactive engineering decisions: restore the library U.FL
keepout, reserve the ground planes, and explicitly fan out three adjacent
mezzanine pins before routing their inner-layer connections. Autorouter
completion is never assumed from a successful process exit; the independent
unconnected-net check is required.

Render the actual PCB with KiCad (repeat for the field head):

```sh
xvfb-run -a kicad-cli pcb render --width 1800 --height 1000 \
  --quality high --background opaque --rotate 325,0,25 --zoom 0.9 \
  -o hw/boards/groundlark-hat/3d.png \
  hw/boards/groundlark-hat/groundlark-hat.kicad_pcb
```

The KiCad project opens directly in PCB Editor; use Alt+3 for its interactive 3D
viewer. Stock models require KiCad's 3D packages. Custom envelopes are portable
under `hw/models/`. Prototype render geometry is not mechanical signoff.

Do not use the empty BOM emitted by atopile's automatic picker: this design uses
manual manufacturer parts. The explicit per-board `bom.csv` files are the review
BOMs. No purchase, assembly order or board fabrication was submitted.

Render the optional pressure sensor population with `python3 hw/tools/render_option.py`. This changes only a temporary render board; U3 stays DNP in the delivered assembly.

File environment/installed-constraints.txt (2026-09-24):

annotated-doc==0.0.5
annotated-types==0.8.0
anthropic==1.8.0
antlr4-python3-runtime==4.13.2
anyio==4.15.1
arrow==1.4.0
atopile==0.15.9
atopile-easyeda2kicad==0.9.9
atopile-kicad-python==0.5.1
attrs==26.1.0
binaryornot==0.6.0
black==26.5.1
case-converter==1.2.0
cattrs==26.2.0
certifi==2026.7.22
cffi==2.1.1
charset-normalizer==3.5.1
click==8.5.0
contourpy==1.4.0
cookiecutter==2.7.1
cryptography==50.0.1
cycler==0.12.1
dataclasses-json==0.6.7
deprecated==1.2.18
docstring-parser==0.18.0
fake-useragent==2.2.0
fastapi==0.141.1
fastapi-github-oidc==0.3.0
fonttools==4.66.0
freetype-py==2.5.1
gitdb==4.0.12
gitpython==3.1.62
h11==0.16.0
httpcore==1.0.9
httpcore2==2.13.1
httpx==0.28.1
httpx2==2.13.1
idna==3.20
iniconfig==2.3.0
jaraco-classes==3.4.0
jaraco-context==6.1.2
jaraco-functools==4.6.0
jeepney==0.9.0
jinja2==3.1.6
jiter==0.17.0
jsonschema==4.26.0
jsonschema-specifications==2025.9.1
keyring==25.7.0
kicadcliwrapper==1.1.1
kiwisolver==1.5.1
lsprotocol==2025.0.0
markdown-it-py==4.2.0
markupsafe==3.0.3
marshmallow==3.26.2
matplotlib==3.11.2
mcp==2.2.0
mcp-types==2.2.0
mdurl==0.1.2
more-itertools==11.1.0
mypy-extensions==1.1.0
nanobind==3.1.0
natsort==8.4.0
numpy==2.5.3
openai==3.19.1
opentelemetry-api==1.44.0
ordered-set==4.1.0
packaging==26.3
pathspec==1.1.1
pathvalidate==3.3.1
pillow==12.3.0
platformdirs==4.11.12
pluggy==1.6.0
prompt-toolkit==3.0.51
protobuf==5.29.6
psutil==7.2.2
pyaaf2==1.7.1
pycparser==3.0
pydantic==2.13.5
pydantic-core==2.46.5
pydantic-settings==2.15.0
pygls==2.1.1
pygments==2.21.0
pyjwt==2.15.0
pynng==0.9.0
pyparsing==3.3.3
pytest==9.1.1
python-dateutil==2.9.0.post0
python-dotenv==1.2.3
python-multipart==0.0.32
python-slugify==9.1.1
pytokens==0.4.1
pyyaml==6.0.3
questionary==2.1.1
referencing==0.37.0
requests==2.34.2
rich==15.0.0
rpds-py==2026.6.3
ruamel-yaml==0.19.1
ruff==0.15.22
secretstorage==3.5.0
semver==3.1.0
sexpdata==1.0.2
shapely==2.1.2
shellingham==1.5.4
six==1.17.0
smmap==5.0.3
sniffio==1.3.1
sse-starlette==3.4.11
starlette==1.7.0
text-unidecode==1.3
truststore==0.10.4
typer==0.27.2
typing-extensions==4.16.0
typing-inspect==0.9.0
typing-inspection==0.4.4
tzdata==2026.4
urllib3==2.8.0
uvicorn==0.53.0
watchdog==6.0.0
wcwidth==0.9.1
websockets==17.1
wrapt==1.17.3
zstd==1.5.7.2

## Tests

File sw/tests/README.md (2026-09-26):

# Software validation

The runnable contract suite (`test_contract.py`) uses an independently specified
binary producer fixture and covers semantics, corruption and bounded framing.
Run `./lab.ps1 test -Profile software` from the repository root.

The acquisition, driver and Linux I/O suites run the actual application against
independent expectations: recordings, bus errors, time jumps, malformed frames,
queue limits, disconnects, a real pseudo-terminal and a hung subprocess. The
portable runner retains a bounded demo recording and replay summary.
See [the runtime guide](../../docs/sensor-software.md) for limits and commands.
`test_stimulus.py` checks independent physical/raw-count expectations, control
boundaries, deterministic noise, GNSS movement, timed faults and scenario export
followed by byte-identical regeneration through the actual CLI.

`test_hat_signals.py` exercises a fixed eight-second capture through production
Pi sensor drivers on modeled register/packet buses. It measures frequency, gain,
phase, gravity, gyro/tilt consistency, inter-IMU agreement, GNSS motion and sample
timing. Negative controls prove that physically wrong but well-framed data fail.
The software profile retains `hat-signals.ssrec` and `hat-signals.json`; the UI's
**Test HAT signals** button runs the same analyzer and displays its exact capture.
These thresholds apply to ideal models, not unqualified physical hardware.

`test_fifo.py` checks independent FIFO tag vectors, buffered sample preservation,
counter/timestamp wrap and concealed gaps, overrun rejection, recovery and the
driver-to-runtime-to-recording path. `test_deployment.py` compiles and merges the
Pi overlay with actual device-tree tools, checks five chip selects, refuses wrong
SPI bindings and exercises the GPIO event ABI. `test_measurements.py` checks
known moments, SI conversions and incompatible bench-comparison rejection.
None of these substitutes for live Pi/kernel/sensor qualification.

`test_utc.py` exercises GNSS timing configuration/readback, fragmented/corrupt
UBX, PPS association faults, leap/midnight guards and UTC-copy replay through the
real correlator. `test_bench.py` proves missing measurements/limits cannot pass,
fixed power limits reject violations, and changed evidence hashes are rejected.
See [UTC timing](../../docs/utc-timing.md) and [bench procedure](../../docs/bench-procedure.md).

Keep small deterministic input fixtures here. Put generated logs, traces and
coverage in the portable lab's disposable workspace. Reserve bounded waveform
capture for failures. Add runnable profiles when their implementations and
acceptance criteria exist; do not substitute placeholder passes for integration.

See the [simulation roadmap](../../docs/portable-lab.md#next-simulation-layers).

`test_geophone_timing.py` advances the ADC clock independently of the four-channel
polling loop, with I2C wire delays, clock tolerance and long scheduling stalls.
It checks raw-frame provenance, honest missing/timing fields and continuity
recovery without hardware reset storms. `acquisition-stress.json` retains the
six speed/clock cases; its throughput qualification remains false. The worker
tests also exercise the new conversion-gap exception over actual subprocess IPC.
These tests do not run on a Raspberry Pi or establish its maximum acquisition rate.

`test_fpga_link.py` checks independent framing/CRC, transfer failures at every
stage, late responses, stale results, dropped ACKs, readback faults, ownership
restoration and SIGTERM isolation. `test_fpga_evidence.py` injects timing and
report-coverage failures. The FPGA stage additionally runs the real Python client
against RTL pins, rather than relying only on a byte-level mock peer.
Physical qualification follows the [bench procedure](../../docs/bench-procedure.md).

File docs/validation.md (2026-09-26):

# A2 validation and release gates

The separate FPGA DAQHAT-01 variant has its own [validation report](trenz-hat.md#verification-and-release-limits).
The A2 results below do not certify DAQHAT-01.

**Engineering prototype — not released for fabrication or assembly.** The
circuit is authored in atopile; the native KiCad layout and review schematic
are derived from its compiled pins. Coldfoot silicon was not changed.

A2 puts USB-C only on the remote sensor head and removes the HAT cable interface.
The USB head requires firmware before it can enumerate. See [its circuit and
firmware contract](usb-sensor-head.md). USB connector mechanical holes are marked
on all copper layers in the local footprint, matching KiCad's multilayer PCB
representation; their drill dimensions and positions are unchanged.

## Recorded checks

Environment: atopile 0.15.9/Python 3.14.7, KiCad/pcbnew 9.0.9, ngspice 42,
Freerouting 1.9.0, WSL Ubuntu 24.04. The HAT has six copper layers (In1/In4 GND);
the field head has four (In1/In2 GND). Provisional minimum track/clearance is
0.15 mm, through-via diameter/drill 0.6/0.3 mm, copper-edge clearance 0.3 mm.
These rules are not a selected manufacturer's stackup or acceptance criteria.

| Board | Atopile pins compared | ERC findings | DRC errors | DRC warnings | Unconnected | Tracks/vias |
|---|---:|---:|---:|---:|---:|---:|
| groundlark-hat | 538 | 0 | 0 | 0 | 0 | 2197 |
| groundlark-field-head | 131 | 0 | 0 | 0 | 0 | 348 |

Evidence: each board's `validation.json`, `drc.json`, `erc.json` and exported
`schematic-netlist.xml` under `hw/boards/`. `hw/tools/check_design.py` checks source,
schematic and PCB pin agreement, independent Pi header corner coordinates and
the actual KiCad ERC/DRC engines. Library keepouts omitted during atopile board
conversion are restored before layout checks. No DRC violations are excluded.

- Explicit upstream atopile numeric solver: HAT and field-head rail/component
  constraints pass. The negative 5 V-to-3.6 V IMU case is correctly rejected.
- `hw/tools/check_circuit.py`: compiled pin assignments, source/BOM agreement,
  module bond/connector mapping, supply/clock/reset/UART direction and bypass
  invariants pass. Removed supervisor bypass and incorrect UART supply mutations
  are rejected.
- **27 ngspice cases pass**: rail/load/USB cable corners, I2C rise time, UART RC,
  USB CC resistor corners, ideal buck power stage and behavioral reset.
  See [simulation scope](../hw/simulation/README.md) and the actual decks/logs.
- Native KiCad schematics, assembly previews and 3D renders were visually
  inspected. Custom module/socket bodies are simplified dimensioned envelopes.
- [Artifact hashes](artifact-manifest.json) identify the checked sources and CAD.

The SPICE cases do not simulate MEMS internals, geomagnetic sensitivity,
Coldfoot RTL, vendor regulator control loops or extracted PCB parasitics.
Pin agreement establishes CAD consistency; it does not replace independent
supplier pinout/package review. No firmware, inference, silicon, CDC, EMC,
signal-integrity, magnetic-noise or physical bench qualification is claimed.

## Before fabrication

1. Independently review the run-1 bond map, mating connector orientation,
   current per contact, exact package revisions and ordered parts. Confirm the
   optional DLVR suffix. The selected run-1 module replaces the earlier run-2
   incompatibility; its complete support circuit is now present.
2. Select a fabrication stackup and review routing: power drops/neck-downs,
   decoupling and buck switching loops, copper thermal paths, via return paths,
   USB data pair geometry and GNSS RF impedance. Clean DRC is not SI/PI signoff.
3. Verify Pi model, underside socket, cooler/ports/ribbon cable clearance,
   overhang support and run-1 stack height. The 120 × 56 mm carrier extends
   beyond the normal HAT outline; no HAT+ compliance certification is claimed.
4. Confirm the assumed 200 mA sensor and 600 mA Coldfoot envelopes, capacitor
   DC-bias derating, standby/partial-power behavior and ISO1640 input-low margin.
5. Implement/test USB enumeration, current limits, suspend/resume, timestamped
   sensor transport, EEPROM contents, overlays, acquisition/timestamping and
   the existing Coldfoot runtime integration before system performance claims.
6. Export and independently inspect manufacturing outputs after these reviews.
   No fabrication or assembly order has been placed.

## Bench acceptance

| Area | Required evidence |
|---|---|
| Power | Current-limited startup, regulator stability and transient droop, reset/brownout and all Pi power states |
| Timing/links | Sensor IDs, CRC/FIFO behavior, SPI modes, USB enumeration/suspend and local I2C timing, PPS timestamp uncertainty and 2 Mbaud runtime round trips |
| Motion/level | Axis orientation, known-angle calibration, stationary noise, thermal drift and correlated noise across four IMUs |
| Magnetics | Remote installation offsets, orientation, hard/soft-iron calibration and noise with Pi/fan/Coldfoot active; reference-station comparison |
| Infrasound option | Pressure calibration, noise, reference-volume/leak transfer function, wind response and saturation recovery |
| Coldfoot | Measured rail/contact currents and clocks, then deterministic recorded-input comparisons through its existing runtime |

The remote magnetometer needs its own orientation calibration; the HAT's
inclinometer does not automatically compensate a separately mounted head.
Aurora-related magnetic measurements are not optical aurora detection.
Acquisition/replay and fault tests are implemented in the portable software
profile; see [software evidence and limits](sensor-software.md). These tests
do not qualify USB-head firmware or physical sensor performance.

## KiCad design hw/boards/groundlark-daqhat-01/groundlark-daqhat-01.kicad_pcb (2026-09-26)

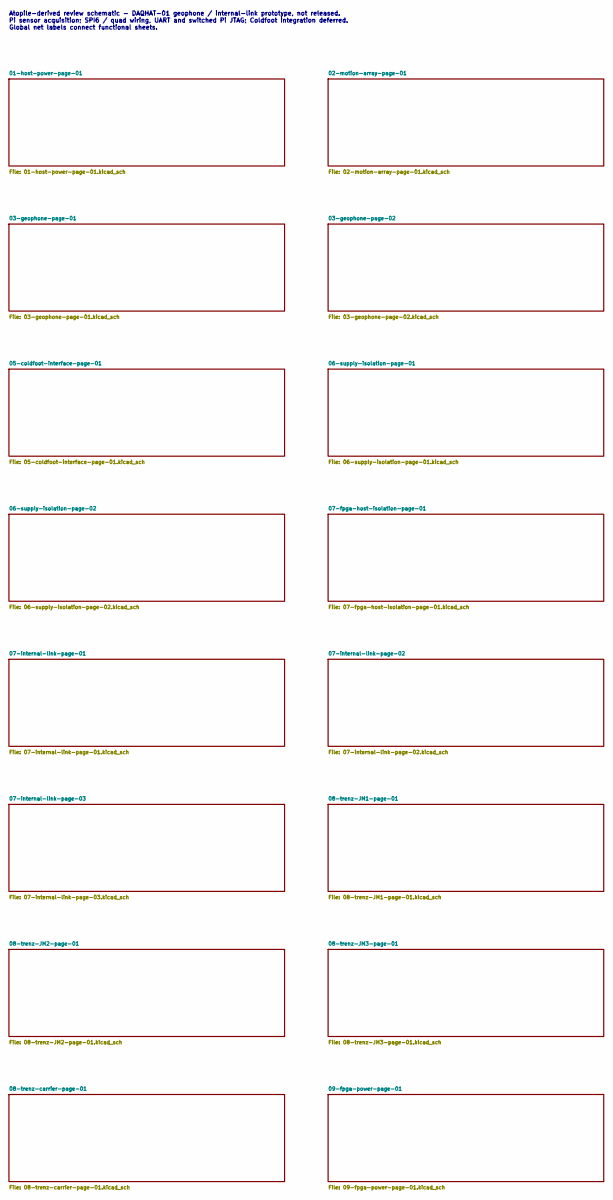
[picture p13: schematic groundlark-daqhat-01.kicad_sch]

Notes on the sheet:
Atopile-derived review schematic - DAQHAT-01 geophone / internal-link prototype, not released. Pi sensor acquisition; SPI6 / quad wiring, UART and switched Pi JTAG; Coldfoot integration deferred. Global net labels connect functional sheets.

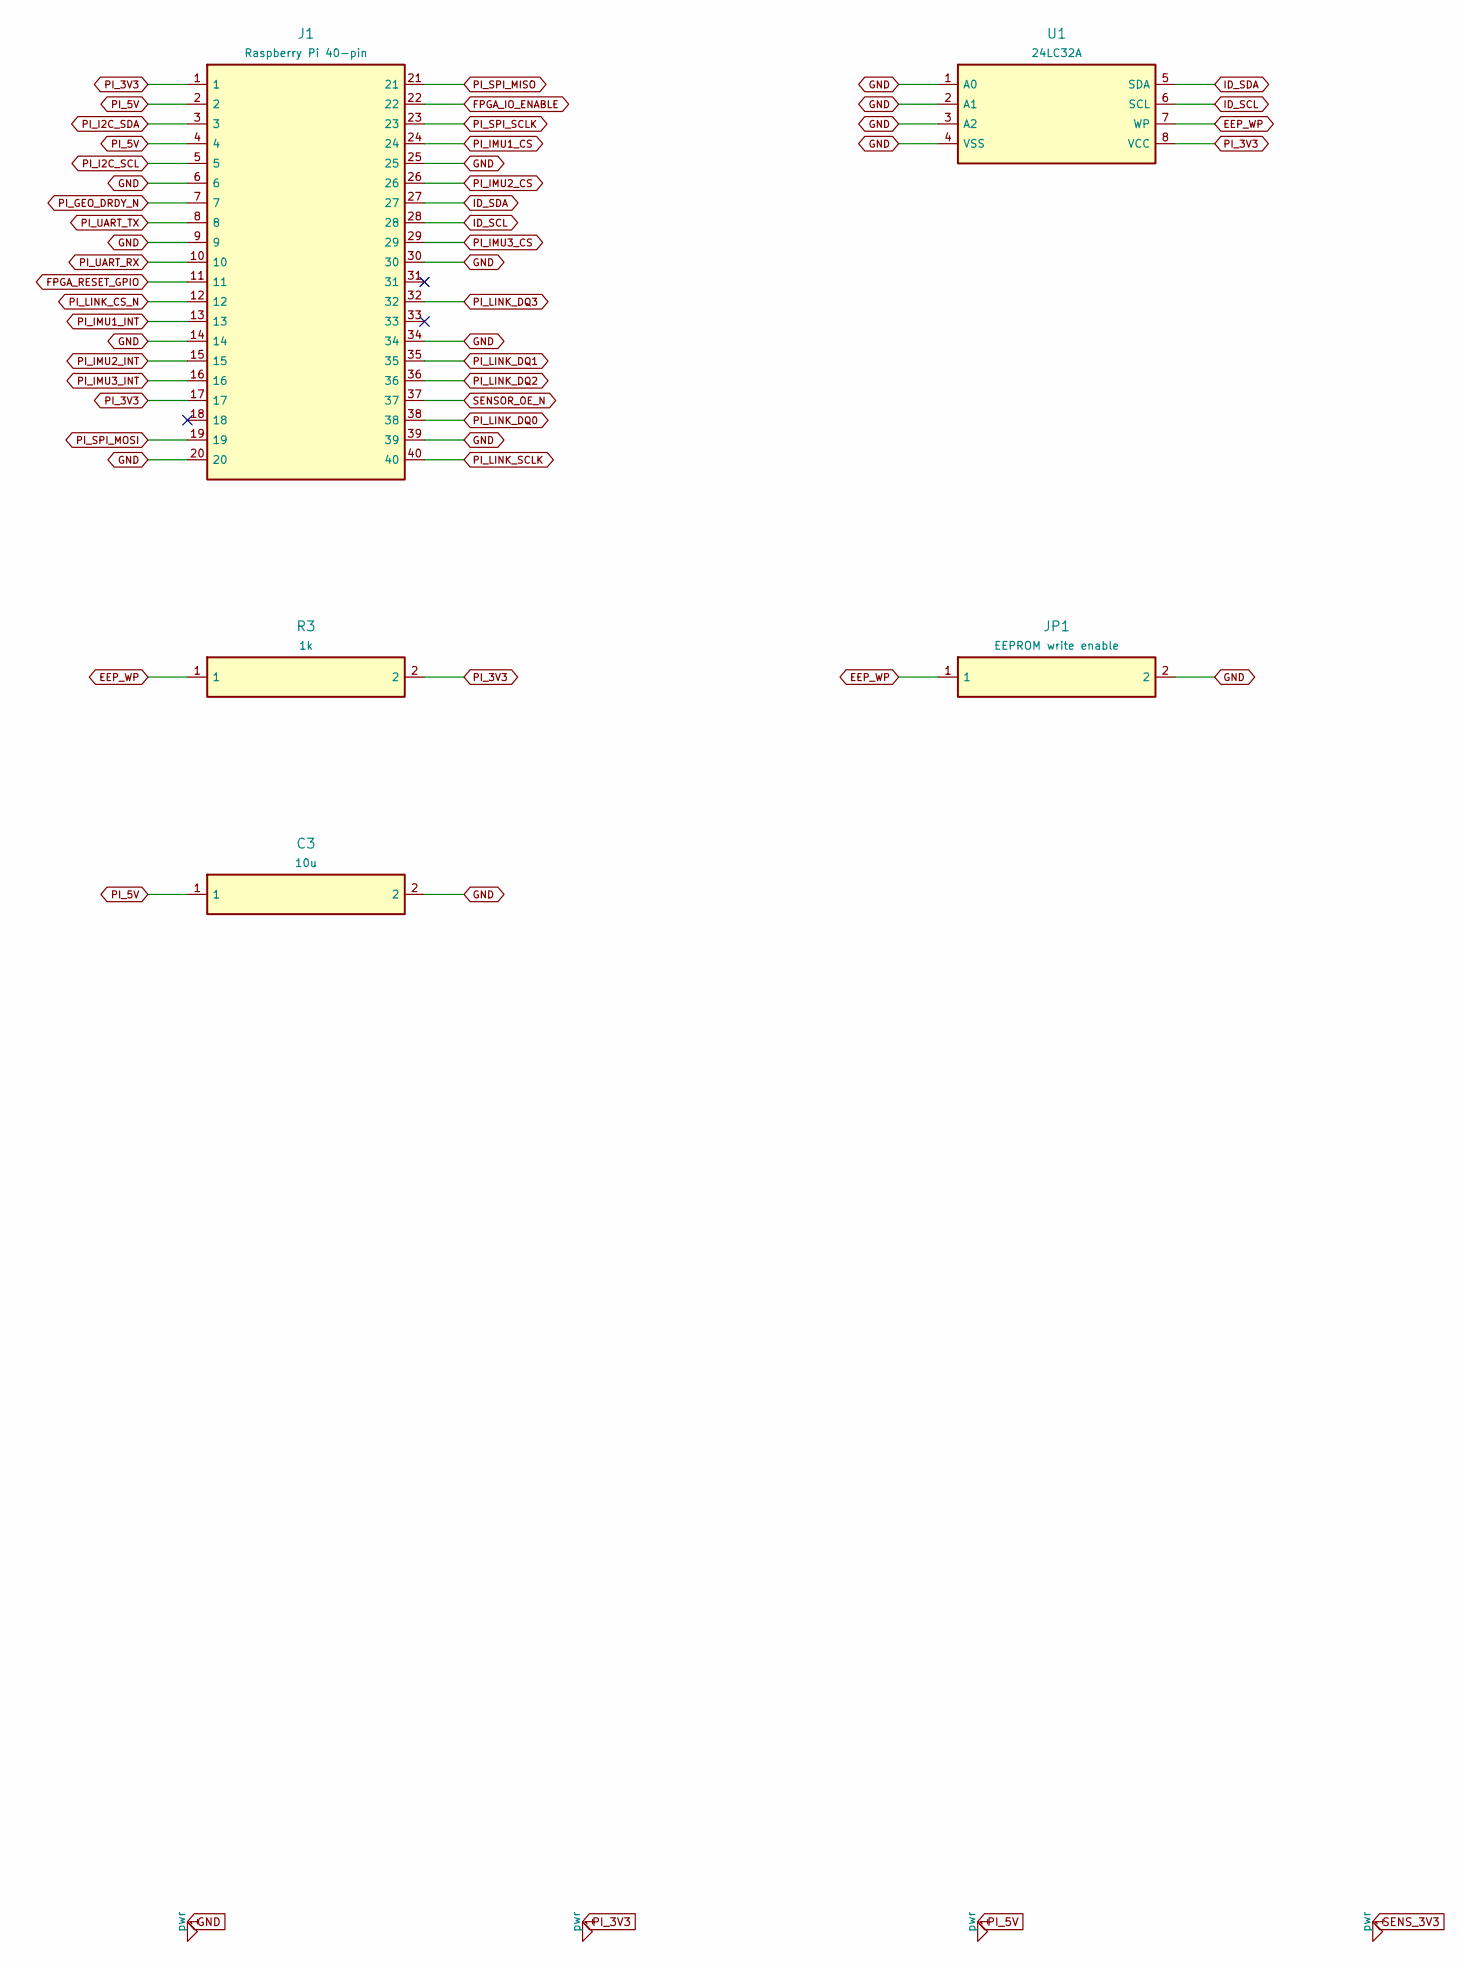
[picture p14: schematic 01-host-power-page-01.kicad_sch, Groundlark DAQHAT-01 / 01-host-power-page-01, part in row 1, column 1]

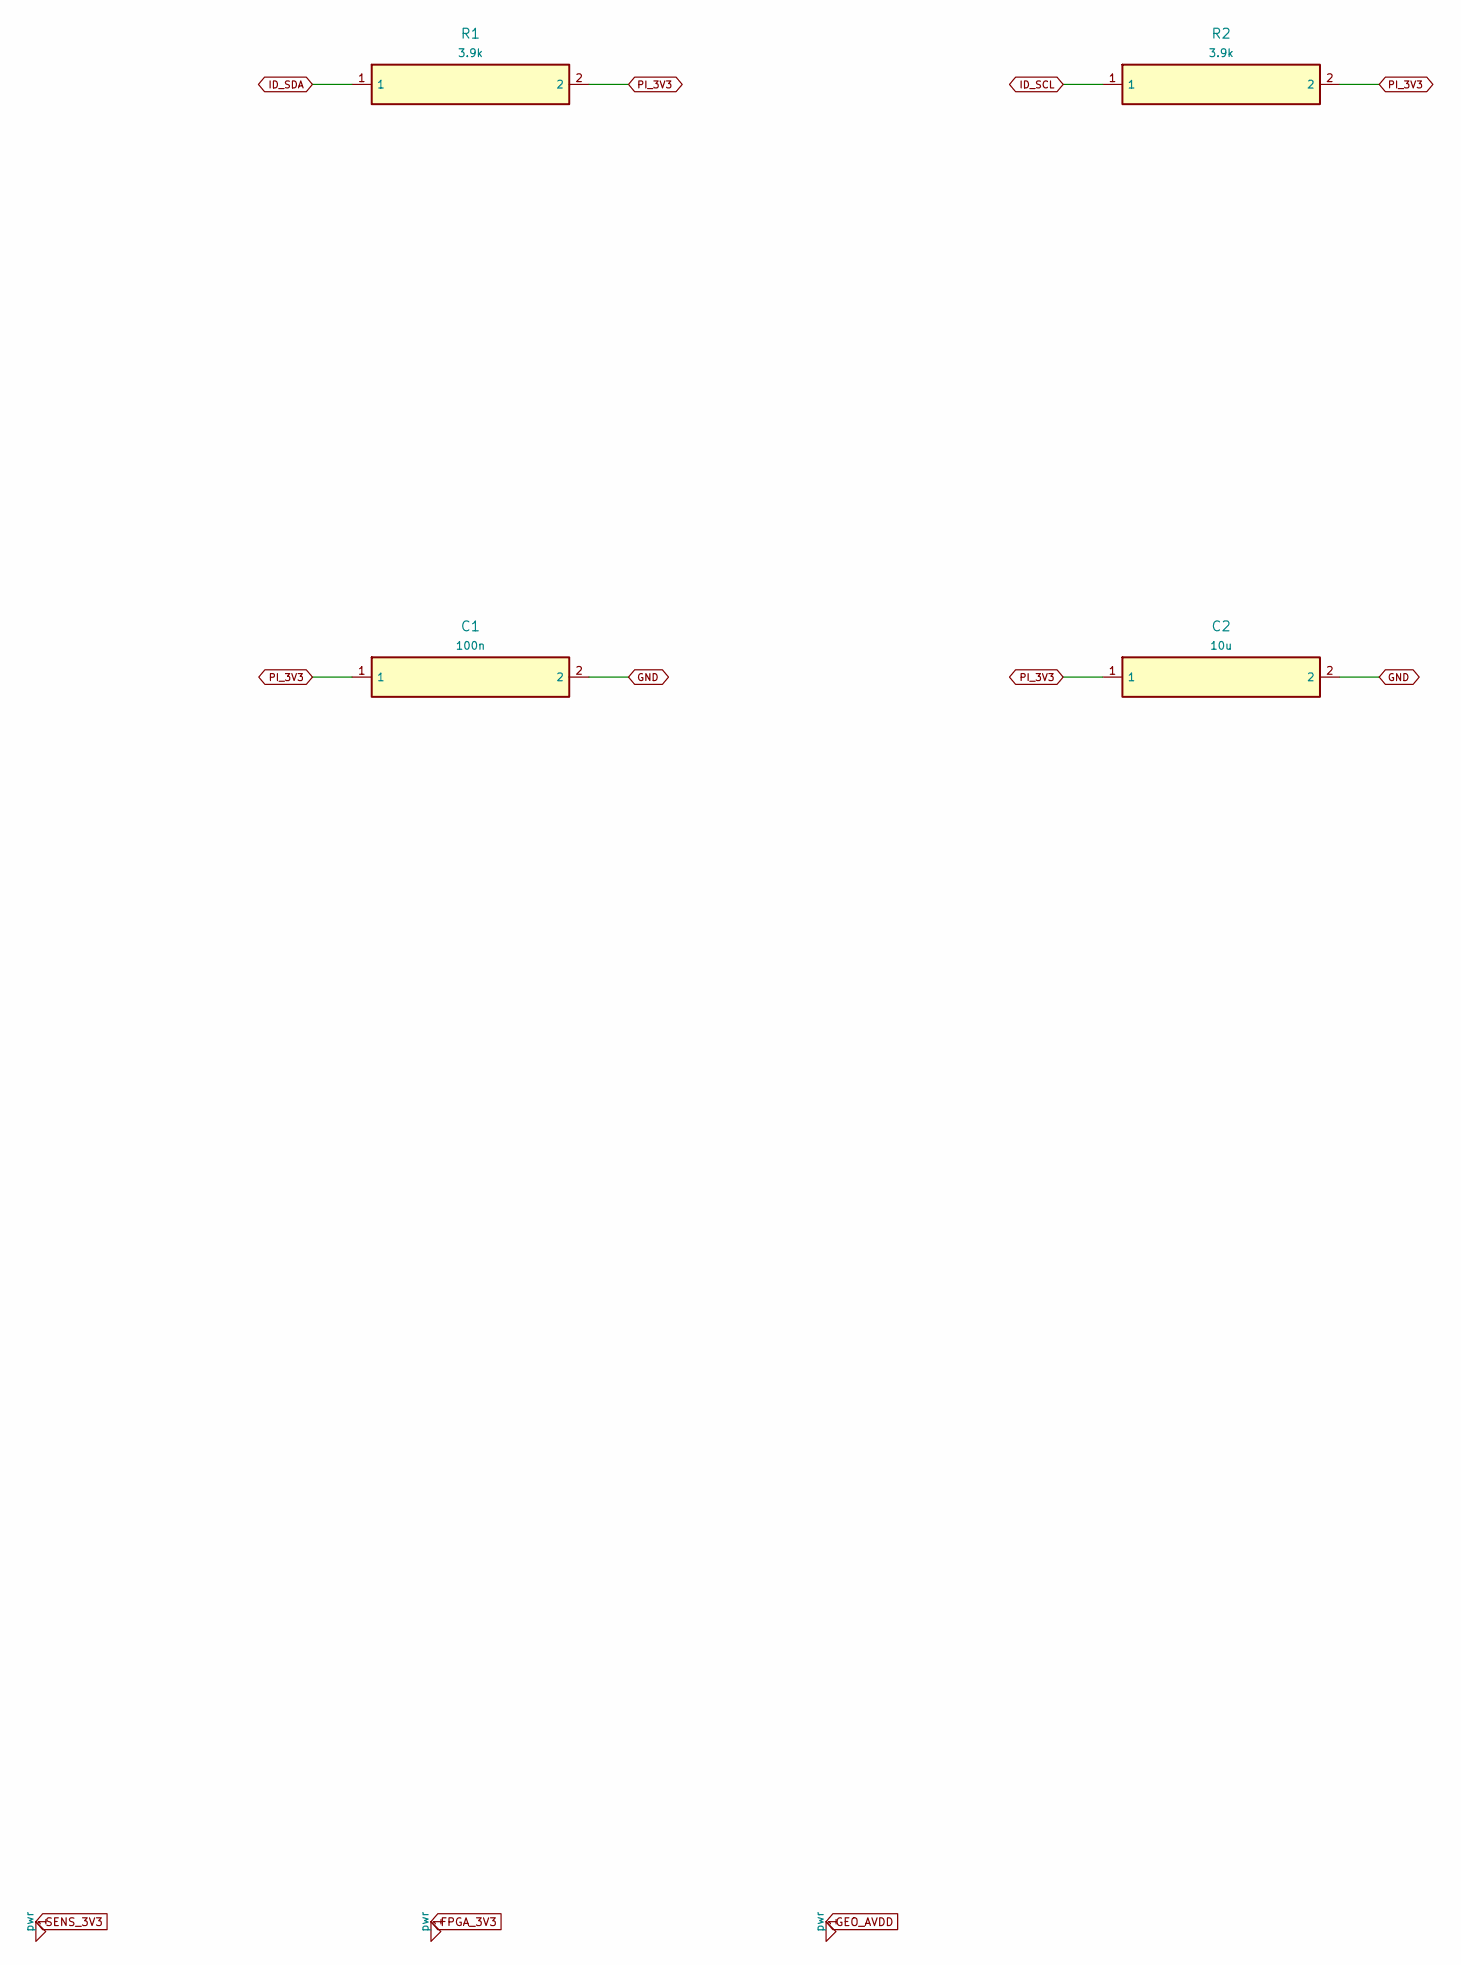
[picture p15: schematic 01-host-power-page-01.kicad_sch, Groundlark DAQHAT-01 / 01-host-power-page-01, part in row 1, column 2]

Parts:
C1: 100n; Capacitor_SMD__C_0603_1608Metric; MPN GRM188R71H104KA93D
C2, C3: 10u; Capacitor_SMD__C_0805_2012Metric; MPN GRM21BR61A106KE19L
J1: Raspberry Pi 40-pin; Connector_PinHeader_2.54mm__PinHeader_2x20_P2.54mm_Vertical; MPN Samtec ESQ-120-23-G-D
JP1: EEPROM write enable; Connector_PinHeader_2.54mm__PinHeader_1x02_P2.54mm_Vertical; MPN EEPROM write enable
R1, R2: 3.9k; Resistor_SMD__R_0603_1608Metric; MPN RC0603FR-073K9L
R3: 1k; Resistor_SMD__R_0603_1608Metric; MPN RC0603FR-071KL
U1: 24LC32A; Package_SO__SOIC-8_3.9x4.9mm_P1.27mm; MPN 24LC32A-I/SN

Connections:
18: J1.18
31: J1.31
33: J1.33
EEP_WP: JP1.1, R3.1, U1.7 (WP)
FPGA_IO_ENABLE: J1.22; also elsewhere on the board
FPGA_RESET_GPIO: J1.11; also elsewhere on the board
GND: C1.2, C2.2, C3.2, J1.6, J1.9, J1.14, J1.20, J1.25, J1.30, J1.34, J1.39, JP1.2, U1.1 (A0), U1.2 (A1), U1.3 (A2), U1.4 (VSS); also elsewhere on the board
ID_SCL: J1.28, R2.1, U1.6 (SCL)
ID_SDA: J1.27, R1.1, U1.5 (SDA)
PI_3V3: C1.1, C2.1, J1.1, J1.17, R1.2, R2.2, R3.2, U1.8 (VCC); also elsewhere on the board
PI_5V: C3.1, J1.2, J1.4; also elsewhere on the board
PI_GEO_DRDY_N: J1.7; also elsewhere on the board
PI_I2C_SCL: J1.5; also elsewhere on the board
PI_I2C_SDA: J1.3; also elsewhere on the board
PI_IMU1_CS: J1.24; also elsewhere on the board
PI_IMU1_INT: J1.13; also elsewhere on the board
PI_IMU2_CS: J1.26; also elsewhere on the board
PI_IMU2_INT: J1.15; also elsewhere on the board
PI_IMU3_CS: J1.29; also elsewhere on the board
PI_IMU3_INT: J1.16; also elsewhere on the board
PI_LINK_CS_N: J1.12; also elsewhere on the board
PI_LINK_DQ0: J1.38; also elsewhere on the board
PI_LINK_DQ1: J1.35; also elsewhere on the board
PI_LINK_DQ2: J1.36; also elsewhere on the board
PI_LINK_DQ3: J1.32; also elsewhere on the board
PI_LINK_SCLK: J1.40; also elsewhere on the board
PI_SPI_MISO: J1.21; also elsewhere on the board
PI_SPI_MOSI: J1.19; also elsewhere on the board
PI_SPI_SCLK: J1.23; also elsewhere on the board
PI_UART_RX: J1.10; also elsewhere on the board
PI_UART_TX: J1.8; also elsewhere on the board
SENSOR_OE_N: J1.37; also elsewhere on the board

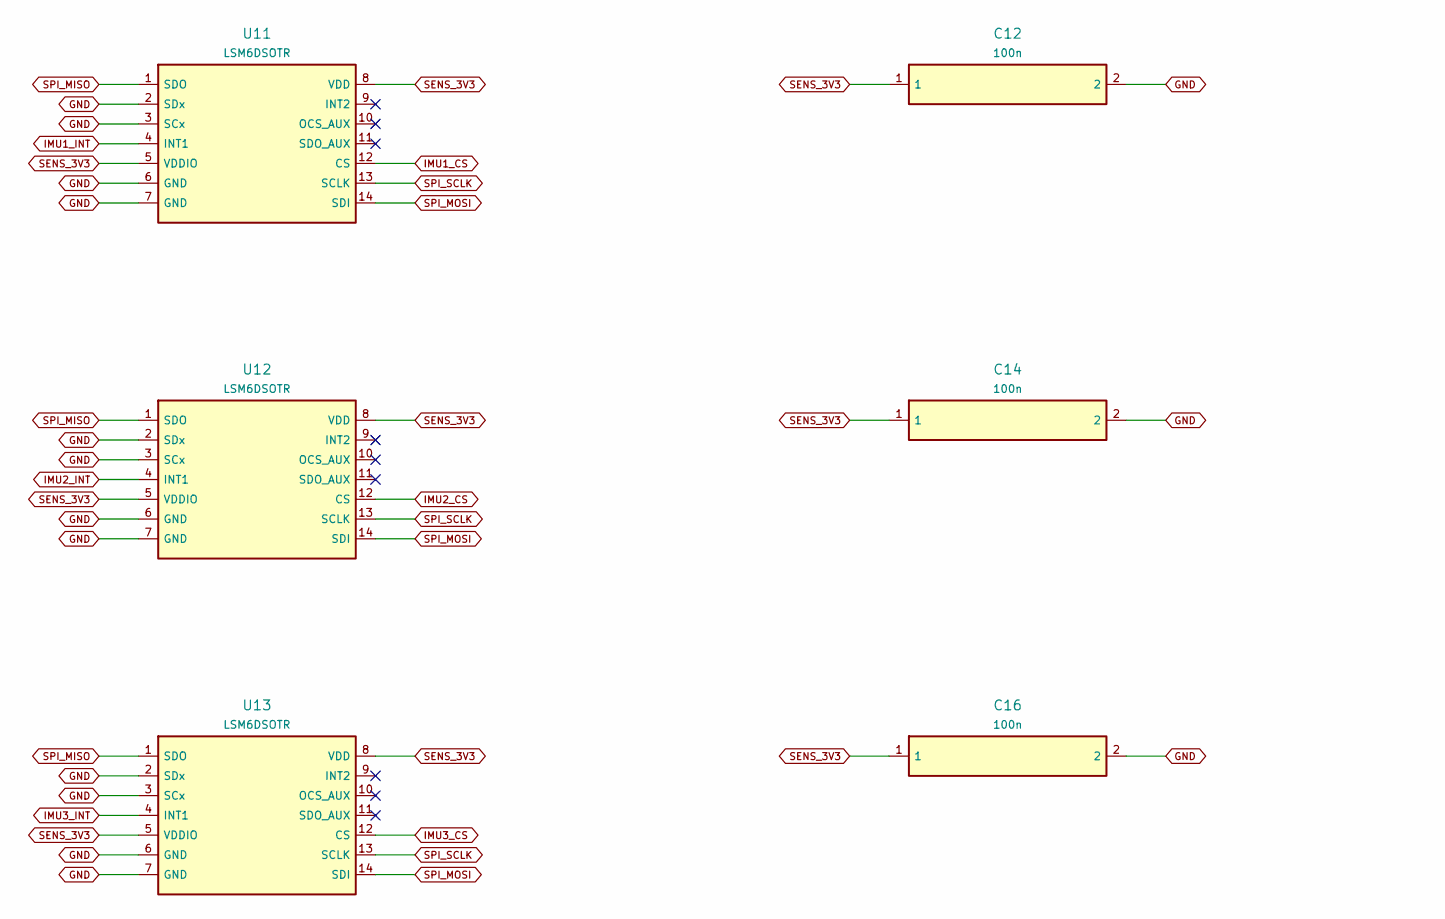
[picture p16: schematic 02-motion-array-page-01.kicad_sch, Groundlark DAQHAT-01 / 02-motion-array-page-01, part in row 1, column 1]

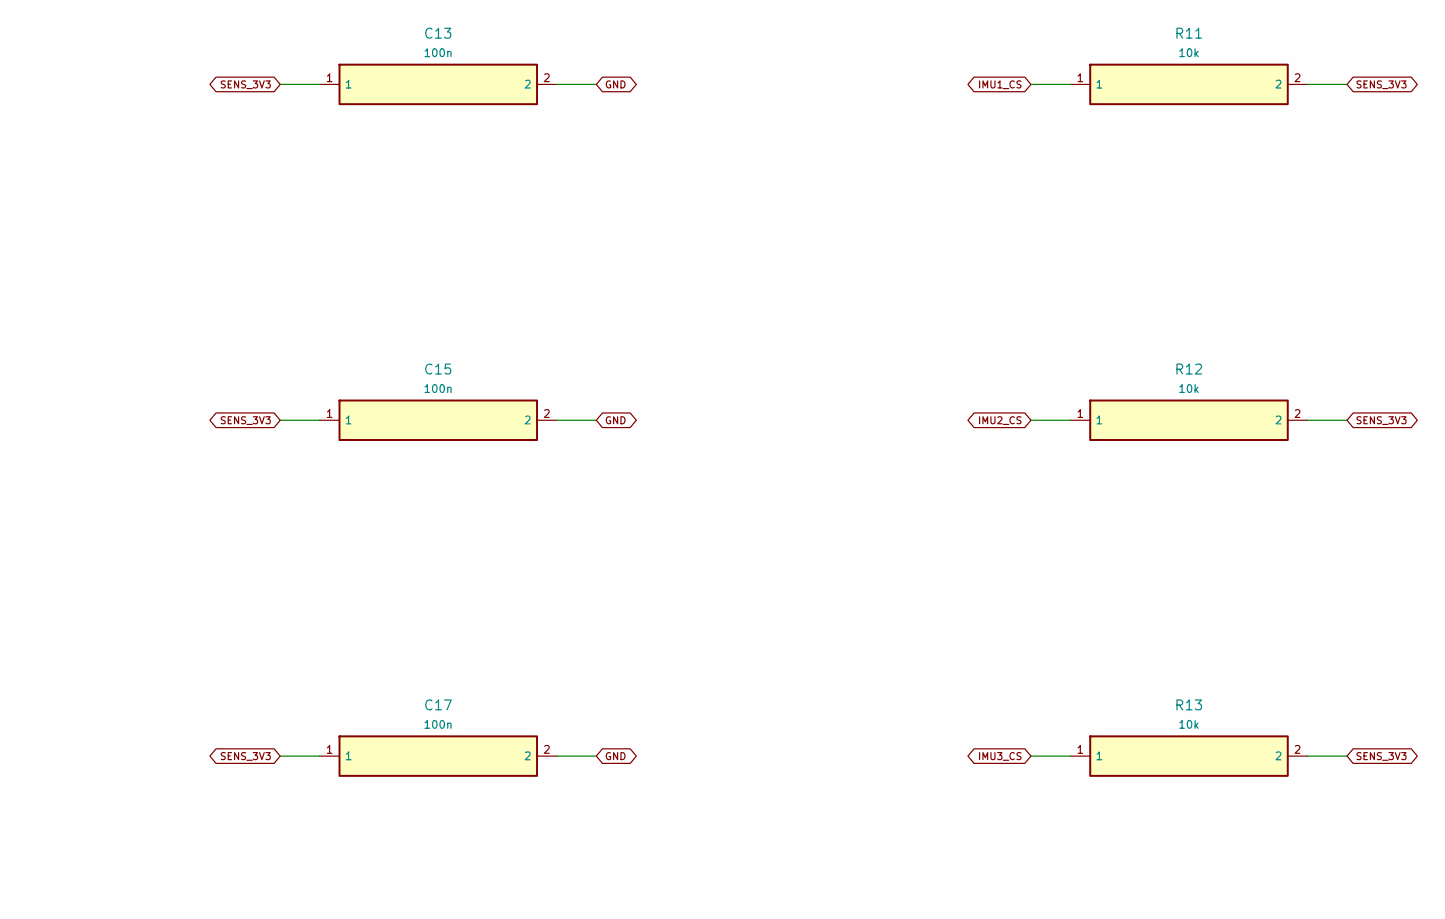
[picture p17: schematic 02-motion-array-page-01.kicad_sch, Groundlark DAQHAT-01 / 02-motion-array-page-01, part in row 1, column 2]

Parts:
C12, C13, C14, C15, C16, C17: 100n; Capacitor_SMD__C_0402_1005Metric; MPN GRM155R71C104KA88D
R11, R12, R13: 10k; Resistor_SMD__R_0603_1608Metric; MPN RC0603FR-0710KL
U11, U12, U13: LSM6DSOTR; Package_LGA__LGA-14_3x2.5mm_P0.5mm_LayoutBorder3x4y; MPN LSM6DSOTR

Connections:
GND: C12.2, C13.2, C14.2, C15.2, C16.2, C17.2, U11.2 (SDx), U11.3 (SCx), U11.6 (GND), U11.7 (GND), U12.2 (SDx), U12.3 (SCx), U12.6 (GND), U12.7 (GND), U13.2 (SDx), U13.3 (SCx), U13.6 (GND), U13.7 (GND); also elsewhere on the board
IMU1_CS: R11.1, U11.12 (CS); also elsewhere on the board
IMU1_INT: U11.4 (INT1); also elsewhere on the board
IMU2_CS: R12.1, U12.12 (CS); also elsewhere on the board
IMU2_INT: U12.4 (INT1); also elsewhere on the board
IMU3_CS: R13.1, U13.12 (CS); also elsewhere on the board
IMU3_INT: U13.4 (INT1); also elsewhere on the board
SENS_3V3: C12.1, C13.1, C14.1, C15.1, C16.1, C17.1, R11.2, R12.2, R13.2, U11.5 (VDDIO), U11.8 (VDD), U12.5 (VDDIO), U12.8 (VDD), U13.5 (VDDIO), U13.8 (VDD); also elsewhere on the board
SPI_MISO: U11.1 (SDO), U12.1 (SDO), U13.1 (SDO); also elsewhere on the board
SPI_MOSI: U11.14 (SDI), U12.14 (SDI), U13.14 (SDI); also elsewhere on the board
SPI_SCLK: U11.13 (SCLK), U12.13 (SCLK), U13.13 (SCLK); also elsewhere on the board
u11-9: U11.9 (INT2)
u11-10: U11.10 (OCS_AUX)
u11-11: U11.11 (SDO_AUX)
u12-9: U12.9 (INT2)
u12-10: U12.10 (OCS_AUX)
u12-11: U12.11 (SDO_AUX)
u13-9: U13.9 (INT2)
u13-10: U13.10 (OCS_AUX)
u13-11: U13.11 (SDO_AUX)

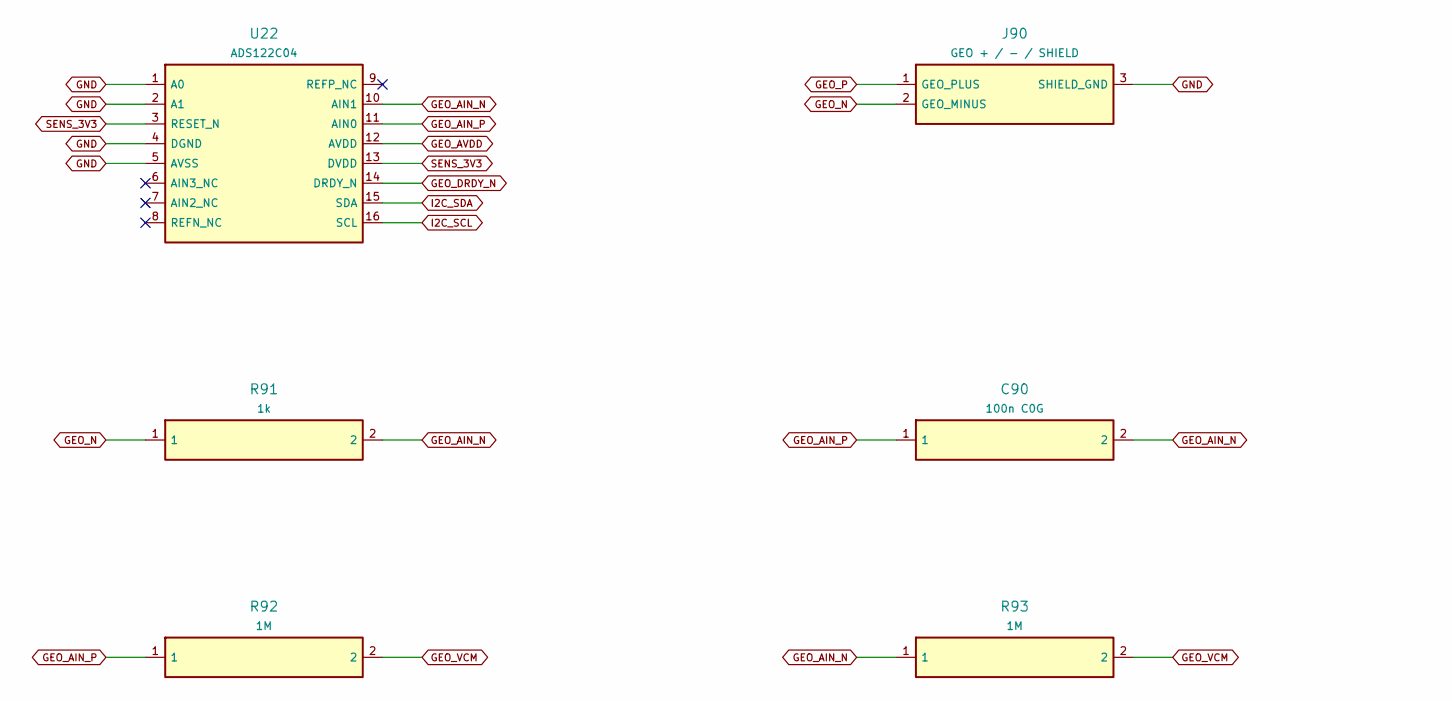
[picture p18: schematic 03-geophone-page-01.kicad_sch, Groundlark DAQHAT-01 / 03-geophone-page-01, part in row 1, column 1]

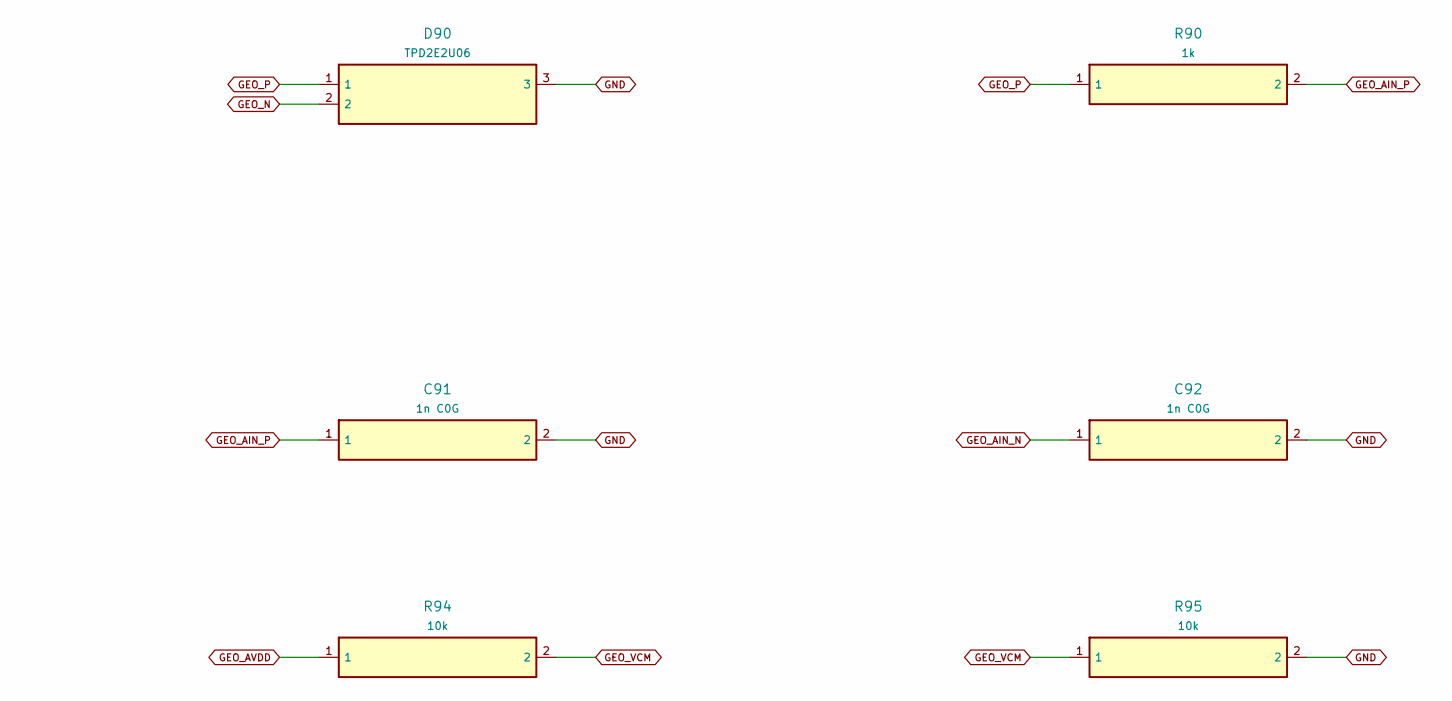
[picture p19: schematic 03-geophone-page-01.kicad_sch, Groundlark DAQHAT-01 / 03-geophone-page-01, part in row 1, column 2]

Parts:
C90: 100n C0G; Capacitor_SMD__C_1206_3216Metric; MPN C3216C0G1H104J160AA
C91, C92: 1n C0G; Capacitor_SMD__C_0603_1608Metric; MPN C0603C102J5GACTU
D90: TPD2E2U06; Package_TO_SOT_SMD__SOT-323_SC-70; MPN TPD2E2U06DCKR
J90: GEO + / - / SHIELD; Connector_Phoenix_MC__PhoenixContact_MCV_1,5_3-G-3.81_1x03_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; MPN 1803439
R90, R91: 1k; Resistor_SMD__R_0603_1608Metric; MPN RC0603FR-071KL
R92, R93: 1M; Resistor_SMD__R_0603_1608Metric; MPN RC0603FR-071ML
R94, R95: 10k; Resistor_SMD__R_0603_1608Metric; MPN RC0603FR-0710KL
U22: ADS122C04; Package_SO__TSSOP-16_4.4x5mm_P0.65mm; MPN ADS122C04IPWR

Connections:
GEO_AIN_N: C90.2, C92.1, R91.2, R93.1, U22.10 (AIN1)
GEO_AIN_P: C90.1, C91.1, R90.2, R92.1, U22.11 (AIN0)
GEO_AVDD: R94.1, U22.12 (AVDD); also elsewhere on the board
GEO_DRDY_N: U22.14 (DRDY_N); also elsewhere on the board
GEO_N: D90.2, J90.2 (GEO_MINUS), R91.1
GEO_P: D90.1, J90.1 (GEO_PLUS), R90.1
GEO_VCM: R92.2, R93.2, R94.2, R95.1; also elsewhere on the board
GND: C91.2, C92.2, D90.3, J90.3 (SHIELD_GND), R95.2, U22.1 (A0), U22.2 (A1), U22.4 (DGND), U22.5 (AVSS); also elsewhere on the board
I2C_SCL: U22.16 (SCL); also elsewhere on the board
I2C_SDA: U22.15 (SDA); also elsewhere on the board
SENS_3V3: U22.3 (RESET_N), U22.13 (DVDD); also elsewhere on the board
u22-6: U22.6 (AIN3_NC)
u22-7: U22.7 (AIN2_NC)
u22-8: U22.8 (REFN_NC)
u22-9: U22.9 (REFP_NC)

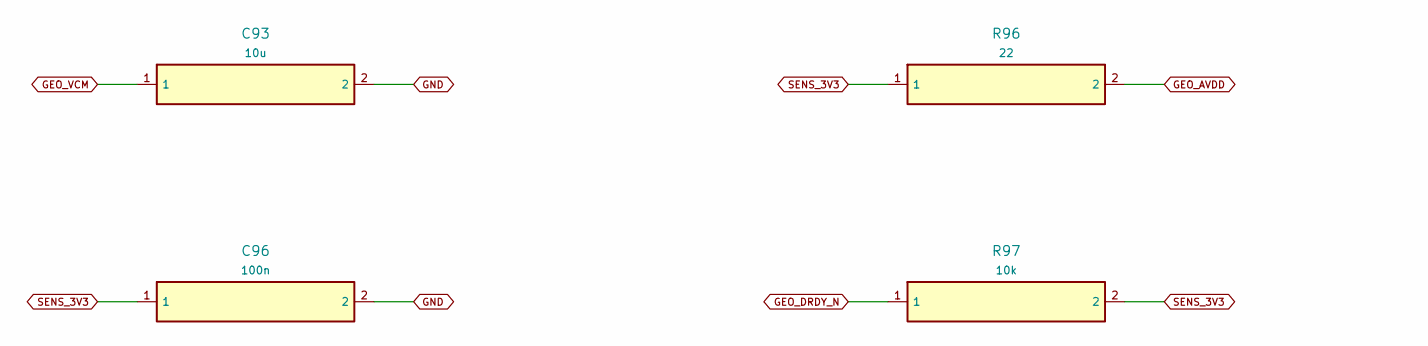
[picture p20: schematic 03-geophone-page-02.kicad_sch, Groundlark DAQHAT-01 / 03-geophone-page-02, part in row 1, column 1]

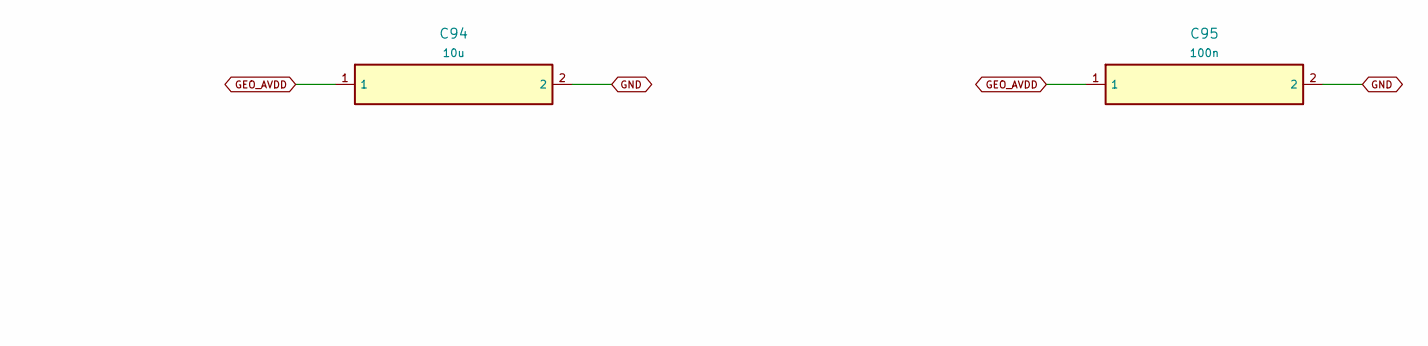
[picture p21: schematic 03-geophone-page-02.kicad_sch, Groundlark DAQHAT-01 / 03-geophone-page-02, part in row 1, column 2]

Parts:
C93, C94: 10u; Capacitor_SMD__C_0805_2012Metric; MPN GRM21BR61A106KE19L
C95, C96: 100n; Capacitor_SMD__C_0603_1608Metric; MPN GRM188R71H104KA93D
R96: 22; Resistor_SMD__R_0603_1608Metric; MPN RC0603FR-0722RL
R97: 10k; Resistor_SMD__R_0603_1608Metric; MPN RC0603FR-0710KL

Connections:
GEO_AVDD: C94.1, C95.1, R96.2; also elsewhere on the board
GEO_DRDY_N: R97.1; also elsewhere on the board
GEO_VCM: C93.1; also elsewhere on the board
GND: C93.2, C94.2, C95.2, C96.2; also elsewhere on the board
SENS_3V3: C96.1, R96.1, R97.2; also elsewhere on the board

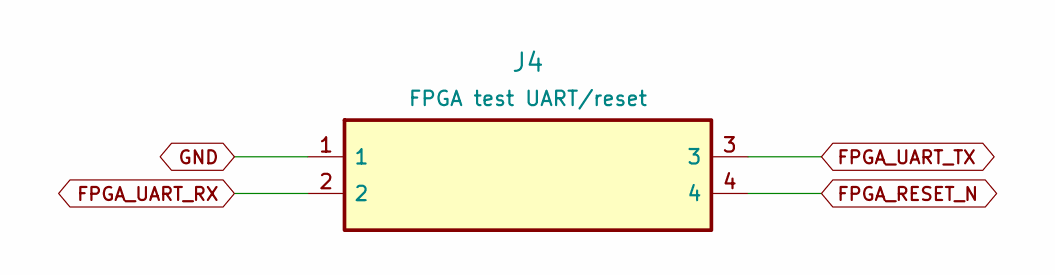
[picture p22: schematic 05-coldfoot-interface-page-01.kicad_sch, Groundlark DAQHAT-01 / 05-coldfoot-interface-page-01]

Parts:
J4: FPGA test UART/reset; Connector_PinHeader_2.54mm__PinHeader_1x04_P2.54mm_Vertical; MPN Coldfoot UART service ONLY

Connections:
FPGA_RESET_N: J4.4; also elsewhere on the board
FPGA_UART_RX: J4.2; also elsewhere on the board
FPGA_UART_TX: J4.3; also elsewhere on the board
GND: J4.1; also elsewhere on the board

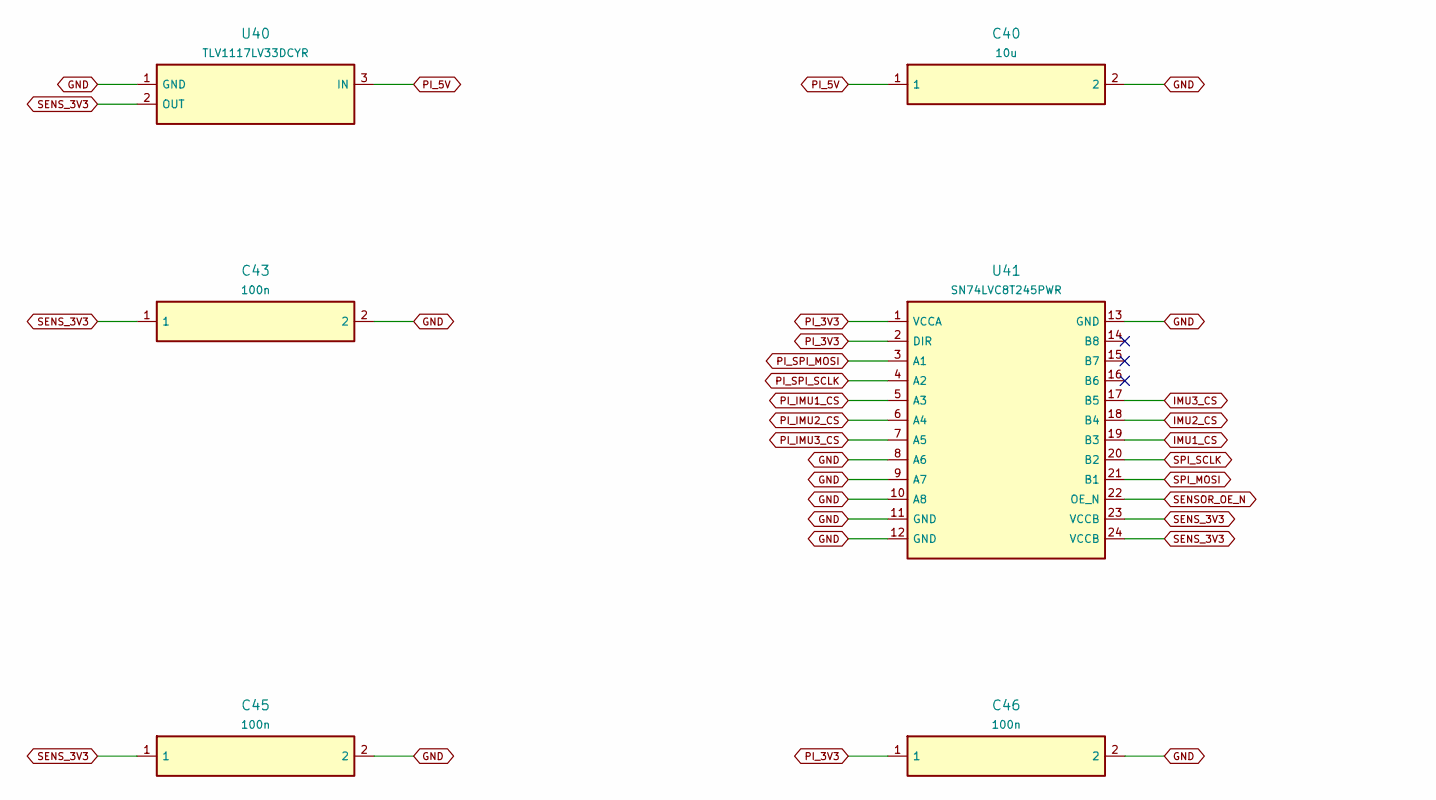
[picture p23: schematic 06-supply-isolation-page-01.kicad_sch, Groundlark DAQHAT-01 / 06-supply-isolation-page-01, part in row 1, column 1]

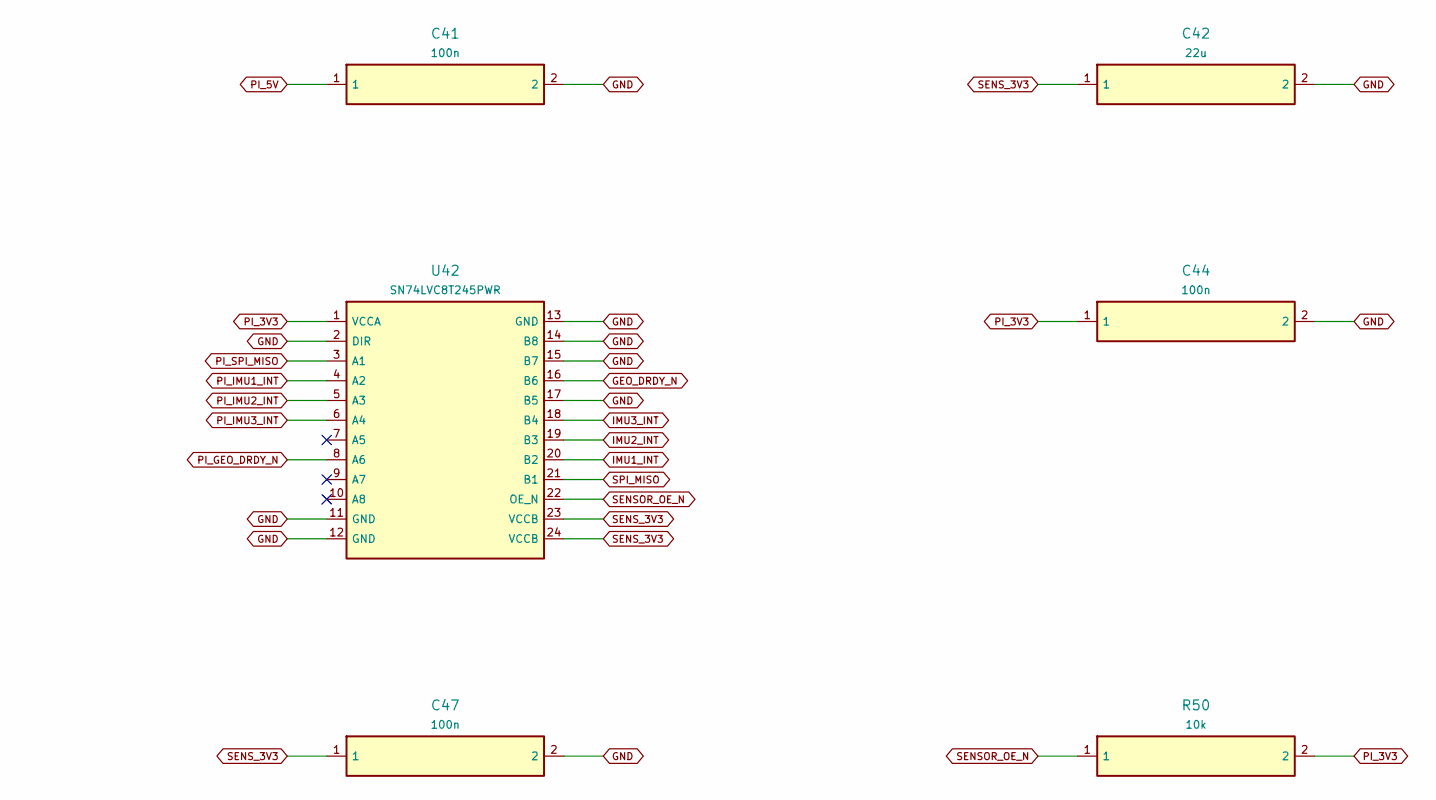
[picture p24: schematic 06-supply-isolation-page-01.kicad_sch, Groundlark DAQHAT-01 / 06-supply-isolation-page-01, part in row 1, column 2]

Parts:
C40: 10u; Capacitor_SMD__C_0805_2012Metric; MPN GRM21BR61A106KE19L
C41, C43, C44, C45, C46, C47: 100n; Capacitor_SMD__C_0603_1608Metric; MPN GRM188R71H104KA93D
C42: 22u; Capacitor_SMD__C_1206_3216Metric; MPN GRM31CR61A226KE19L
R50: 10k; Resistor_SMD__R_0603_1608Metric; MPN RC0603FR-0710KL
U40: TLV1117LV33DCYR; Package_TO_SOT_SMD__SOT-223-3_TabPin2; MPN TLV1117LV33DCYR
U41, U42: SN74LVC8T245PWR; Package_SO__TSSOP-24_4.4x7.8mm_P0.65mm; MPN SN74LVC8T245PWR

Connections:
GEO_DRDY_N: U42.16 (B6); also elsewhere on the board
GND: C40.2, C41.2, C42.2, C43.2, C44.2, C45.2, C46.2, C47.2, U40.1 (GND), U41.8 (A6), U41.9 (A7), U41.10 (A8), U41.11 (GND), U41.12 (GND), U41.13 (GND), U42.2 (DIR), U42.11 (GND), U42.12 (GND), U42.13 (GND), U42.14 (B8), U42.15 (B7), U42.17 (B5); also elsewhere on the board
IMU1_CS: U41.19 (B3); also elsewhere on the board
IMU1_INT: U42.20 (B2); also elsewhere on the board
IMU2_CS: U41.18 (B4); also elsewhere on the board
IMU2_INT: U42.19 (B3); also elsewhere on the board
IMU3_CS: U41.17 (B5); also elsewhere on the board
IMU3_INT: U42.18 (B4); also elsewhere on the board
PI_3V3: C44.1, C46.1, R50.2, U41.1 (VCCA), U41.2 (DIR), U42.1 (VCCA); also elsewhere on the board
PI_5V: C40.1, C41.1, U40.3 (IN); also elsewhere on the board
PI_GEO_DRDY_N: U42.8 (A6); also elsewhere on the board
PI_IMU1_CS: U41.5 (A3); also elsewhere on the board
PI_IMU1_INT: U42.4 (A2); also elsewhere on the board
PI_IMU2_CS: U41.6 (A4); also elsewhere on the board
PI_IMU2_INT: U42.5 (A3); also elsewhere on the board
PI_IMU3_CS: U41.7 (A5); also elsewhere on the board
PI_IMU3_INT: U42.6 (A4); also elsewhere on the board
PI_SPI_MISO: U42.3 (A1); also elsewhere on the board
PI_SPI_MOSI: U41.3 (A1); also elsewhere on the board
PI_SPI_SCLK: U41.4 (A2); also elsewhere on the board
SENSOR_OE_N: R50.1, U41.22 (OE_N), U42.22 (OE_N); also elsewhere on the board
SENS_3V3: C42.1, C43.1, C45.1, C47.1, U40.2 (OUT), U41.23 (VCCB), U41.24 (VCCB), U42.23 (VCCB), U42.24 (VCCB); also elsewhere on the board
SPI_MISO: U42.21 (B1); also elsewhere on the board
SPI_MOSI: U41.21 (B1); also elsewhere on the board
SPI_SCLK: U41.20 (B2); also elsewhere on the board
u41-14: U41.14 (B8)
u41-15: U41.15 (B7)
u41-16: U41.16 (B6)
u42-7: U42.7 (A5)
u42-9: U42.9 (A7)
u42-10: U42.10 (A8)



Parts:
C48, C49: 100n; Capacitor_SMD__C_0603_1608Metric; MPN GRM188R71H104KA93D
R51: 100k; Resistor_SMD__R_0603_1608Metric; MPN RC0603FR-07100KL
R52, R53: 4.7k; Resistor_SMD__R_0603_1608Metric; MPN RC0603FR-074K7L
TP1: SENS_3V3; TestPoint__TestPoint_Pad_D1.5mm; MPN SENS_3V3
TP2: GND; TestPoint__TestPoint_Pad_D1.5mm; MPN GND
TP4: SENSOR_OE_N; TestPoint__TestPoint_Pad_D1.5mm; MPN SENSOR_OE_N
U43: ISO1640BDR; Package_SO__SOIC-8_3.9x4.9mm_P1.27mm; MPN ISO1640BDR

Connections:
GND: C48.2, C49.2, R51.2, TP2.1, U43.4 (GND1), U43.5 (GND2); also elsewhere on the board
I2C_SCL: R53.1, U43.6 (SCL2); also elsewhere on the board
I2C_SDA: R52.1, U43.7 (SDA2); also elsewhere on the board
PI_3V3: C48.1, U43.1 (VCC1); also elsewhere on the board
PI_I2C_SCL: U43.3 (SCL1); also elsewhere on the board
PI_I2C_SDA: U43.2 (SDA1); also elsewhere on the board
SENSOR_OE_N: TP4.1; also elsewhere on the board
SENS_3V3: C49.1, R52.2, R53.2, TP1.1, U43.8 (VCC2); also elsewhere on the board
SPI_MISO: R51.1; also elsewhere on the board

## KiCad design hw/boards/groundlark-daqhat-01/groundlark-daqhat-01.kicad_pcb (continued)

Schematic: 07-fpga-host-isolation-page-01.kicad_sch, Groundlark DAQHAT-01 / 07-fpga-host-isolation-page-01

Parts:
C75, C76, C77: 100n; Capacitor_SMD__C_0603_1608Metric; MPN GRM188R71H104KA93D
Q1: 2N7002; Package_TO_SOT_SMD__SOT-23; MPN 2N7002
R61: 47; Resistor_SMD__R_0603_1608Metric; MPN RC0603FR-0747RL
R62, R66: 100k; Resistor_SMD__R_0603_1608Metric; MPN RC0603FR-07100KL
R63, R64: 10k; Resistor_SMD__R_0603_1608Metric; MPN RC0603FR-0710KL
R65: 1k; Resistor_SMD__R_0603_1608Metric; MPN RC0603FR-071KL
U51: TXU0202DCUR; Package_SO__VSSOP-8_2.3x2mm_P0.5mm; MPN TXU0202DCUR
U52: TLV803EA30DBZR; Package_TO_SOT_SMD__SOT-23; MPN TLV803EA30DBZR

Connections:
FPGA_3V3: C76.1, C77.1, R63.2, R64.2, U51.7 (VCCB), U52.3 (VDD); also elsewhere on the board
FPGA_IO_ENABLE: R62.1, U51.6 (OE); also elsewhere on the board
FPGA_RESET_GATE: Q1.1 (G), R65.2, R66.1
FPGA_RESET_GPIO: R65.1; also elsewhere on the board
FPGA_RESET_N: Q1.3 (D), R64.1, U52.2 (RESET_N); also elsewhere on the board
FPGA_UART_DRIVE: R61.1, U51.8 (B1Y_OUT)
FPGA_UART_RX: R61.2, R63.1; also elsewhere on the board
FPGA_UART_TX: U51.1 (B2_IN); also elsewhere on the board
GND: C75.2, C76.2, C77.2, Q1.2 (S), R62.2, R66.2, U51.2 (GND), U52.1 (GND); also elsewhere on the board
PI_3V3: C75.1, U51.3 (VCCA); also elsewhere on the board
PI_UART_RX: U51.4 (A2Y_OUT); also elsewhere on the board
PI_UART_TX: U51.5 (A1_IN); also elsewhere on the board

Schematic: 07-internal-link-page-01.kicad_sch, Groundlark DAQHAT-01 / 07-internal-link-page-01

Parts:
C100, C101, C102, C103, C104, C105: 100n; Capacitor_SMD__C_0603_1608Metric; MPN GRM188R71H104KA93D
U100, U101: TMUX1574PWR; Package_SO__TSSOP-16_4.4x5mm_P0.65mm; MPN TMUX1574PWR
U102: TCA9534PWR; Package_SO__TSSOP-16_4.4x5mm_P0.65mm; MPN TCA9534PWR
U103: SN74LVC1G10DCKR; Package_TO_SOT_SMD__SOT-363_SC-70-6; MPN SN74LVC1G10DCKR
U104, U105: TLV809EA30DBZR; Package_TO_SOT_SMD__SOT-23; MPN TLV809EA30DBZR

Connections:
FPGA_3V3: C100.1, C101.1, C103.1, C105.1, U100.16 (VDD), U101.16 (VDD), U103.5 (VCC), U105.3 (VDD); also elsewhere on the board
FPGA_LINK_CS_N: U101.2 (S1A); also elsewhere on the board
FPGA_LINK_DQ0: U100.5 (S2A); also elsewhere on the board
FPGA_LINK_DQ1: U100.11 (S3A); also elsewhere on the board
FPGA_LINK_DQ2: U100.14 (S4A); also elsewhere on the board
FPGA_LINK_DQ3: U101.5 (S2A); also elsewhere on the board
FPGA_LINK_SCLK: U100.2 (S1A); also elsewhere on the board
GND: C100.2, C101.2, C102.2, C103.2, C104.2, C105.2, U100.8 (GND), U101.8 (GND), U101.9 (D3), U101.10 (S3B), U101.11 (S3A), U101.12 (D4), U101.13 (S4B), U101.14 (S4A), U102.1 (A0), U102.2 (A1), U102.3 (A2), U102.6 (P2), U102.7 (P3), U102.8 (GND), U102.9 (P4), U102.10 (P5), U102.11 (P6), U102.12 (P7), U103.2 (GND), U104.1 (GND), U105.1 (GND); also elsewhere on the board
JTAG_TCK: U100.3 (S1B); also elsewhere on the board
JTAG_TDI: U100.6 (S2B); also elsewhere on the board
JTAG_TDO: U100.10 (S3B); also elsewhere on the board
JTAG_TMS: U100.13 (S4B); also elsewhere on the board
LINK_ARMED_REQUEST: U103.1 (A); also elsewhere on the board
LINK_CS_N: U101.4 (D1); also elsewhere on the board
LINK_DQ0: U100.7 (D2); also elsewhere on the board
LINK_DQ1: U100.9 (D3); also elsewhere on the board
LINK_DQ2: U100.12 (D4); also elsewhere on the board
LINK_DQ3: U101.7 (D2); also elsewhere on the board
LINK_FPGA_GOOD: U103.6 (C), U105.2 (RESET_N); also elsewhere on the board
LINK_JTAG_SEL: U100.1 (SEL), U101.1 (SEL), U102.4 (P0_MODE); also elsewhere on the board
LINK_OE_N: U100.15 (EN_N), U101.15 (EN_N), U103.4 (Y); also elsewhere on the board
LINK_PI_GOOD: U103.3 (B), U104.2 (RESET_N); also elsewhere on the board
LINK_REQUEST: U102.5 (P1_ENABLE); also elsewhere on the board
LINK_SCLK: U100.4 (D1); also elsewhere on the board
PI_3V3: C102.1, C104.1, U102.16 (VCC), U104.3 (VDD); also elsewhere on the board
PI_I2C_SCL: U102.14 (SCL); also elsewhere on the board
PI_I2C_SDA: U102.15 (SDA); also elsewhere on the board
u101-3: U101.3 (S1B)
u101-6: U101.6 (S2B)
u102-13: U102.13 (INT_N)

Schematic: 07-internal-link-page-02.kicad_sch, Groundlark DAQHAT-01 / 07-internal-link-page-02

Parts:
R100, R101, R102, R103, R104, R105: 22; Resistor_SMD__R_0603_1608Metric; MPN RC0603FR-0722RL
R106, R107, R108, R109, R110, R111: 10k; Resistor_SMD__R_0603_1608Metric; MPN RC0603FR-0710KL

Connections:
FPGA_3V3: R108.2, R111.2; also elsewhere on the board
FPGA_LINK_CS_N: R111.1; also elsewhere on the board
GND: R106.2, R107.2, R109.2, R110.2; also elsewhere on the board
LINK_CS_N: R104.2; also elsewhere on the board
LINK_DQ0: R101.2; also elsewhere on the board
LINK_DQ1: R102.2; also elsewhere on the board
LINK_DQ2: R103.2; also elsewhere on the board
LINK_DQ3: R105.2; also elsewhere on the board
LINK_FPGA_GOOD: R110.1; also elsewhere on the board
LINK_JTAG_SEL: R106.1; also elsewhere on the board
LINK_OE_N: R108.1; also elsewhere on the board
LINK_PI_GOOD: R109.1; also elsewhere on the board
LINK_REQUEST: R107.1; also elsewhere on the board
LINK_SCLK: R100.2; also elsewhere on the board
PI_LINK_CS_N: R104.1; also elsewhere on the board
PI_LINK_DQ0: R101.1; also elsewhere on the board
PI_LINK_DQ1: R102.1; also elsewhere on the board
PI_LINK_DQ2: R103.1; also elsewhere on the board
PI_LINK_DQ3: R105.1; also elsewhere on the board
PI_LINK_SCLK: R100.1; also elsewhere on the board

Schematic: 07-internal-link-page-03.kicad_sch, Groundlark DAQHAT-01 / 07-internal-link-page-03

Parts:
C106: 100n; Capacitor_SMD__C_0603_1608Metric; MPN GRM188R71H104KA93D
R112, R114, R116, R117: 100k; Resistor_SMD__R_0603_1608Metric; MPN RC0603FR-07100KL
R113, R115: 10k; Resistor_SMD__R_0603_1608Metric; MPN RC0603FR-0710KL
U106: SN74LVC1G08DCKR; Package_TO_SOT_SMD__SOT-353_SC-70-5; MPN SN74LVC1G08DCKR

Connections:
FPGA_3V3: C106.1, R113.2, R115.2, U106.5 (VCC); also elsewhere on the board
FPGA_IO_ENABLE: U106.2 (B); also elsewhere on the board
FPGA_LINK_DQ2: R116.1; also elsewhere on the board
FPGA_LINK_DQ3: R117.1; also elsewhere on the board
FPGA_LINK_SCLK: R112.1; also elsewhere on the board
GND: C106.2, R112.2, R114.2, R116.2, R117.2, U106.3 (GND); also elsewhere on the board
JTAG_TCK: R114.1; also elsewhere on the board
JTAG_TDI: R115.1; also elsewhere on the board
JTAG_TMS: R113.1; also elsewhere on the board
LINK_ARMED_REQUEST: U106.4 (Y); also elsewhere on the board
LINK_REQUEST: U106.1 (A); also elsewhere on the board

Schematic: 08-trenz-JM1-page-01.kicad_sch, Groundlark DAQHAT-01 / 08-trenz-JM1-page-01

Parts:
J80: LSHM-150-04.0-L-DV-A-S-K-TR; TZ_TZ100; MPN LSHM-150-04.0-L-DV-A-S-K-TR

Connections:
3: J80.3
5: J80.5
9: J80.9
11: J80.11
15: J80.15
17: J80.17
20: J80.20
21: J80.21
22: J80.22
23: J80.23
24: J80.24
26: J80.26
28: J80.28
32: J80.32
34: J80.34
35: J80.35
36: J80.36
37: J80.37
38: J80.38
39: J80.39
40: J80.40
41: J80.41
42: J80.42
44: J80.44
45: J80.45
46: J80.46
47: J80.47
48: J80.48
49: J80.49
50: J80.50
51: J80.51
52: J80.52
55: J80.55
56: J80.56
57: J80.57
58: J80.58
59: J80.59
60: J80.60
61: J80.61
62: J80.62
65: J80.65
66: J80.66
67: J80.67
68: J80.68
69: J80.69
70: J80.70
71: J80.71
72: J80.72
75: J80.75
76: J80.76
77: J80.77
78: J80.78
79: J80.79
80: J80.80
81: J80.81
82: J80.82
84: J80.84
85: J80.85
86: J80.86
87: J80.87
88: J80.88
91: J80.91
92: J80.92
93: J80.93
94: J80.94
95: J80.95
96: J80.96
97: J80.97
98: J80.98
99: J80.99
100: J80.100
FPGA_3V3: J80.10, J80.12, J80.13; also elsewhere on the board
FPGA_EN1: J80.27; also elsewhere on the board
FPGA_JTAGEN: J80.90; also elsewhere on the board
FPGA_MODE: J80.31
FPGA_NOSEQ: J80.8; also elsewhere on the board
FPGA_PGOOD: J80.29
FPGA_VIN: J80.2, J80.4, J80.6, J80.14, J80.16; also elsewhere on the board
GND: J80.1, J80.7, J80.19, J80.25, J80.30, J80.33, J80.43, J80.53, J80.54, J80.63, J80.64, J80.73, J80.74, J80.83, J80.89, J80.101; also elsewhere on the board
j80-18: J80.18

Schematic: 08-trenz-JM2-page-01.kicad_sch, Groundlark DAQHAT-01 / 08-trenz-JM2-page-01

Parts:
J81: LSHM-150-04.0-L-DV-A-S-K-TR; TZ_TZ100; MPN LSHM-150-04.0-L-DV-A-S-K-TR

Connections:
6: J81.6
16: J81.16
25: J81.25
27: J81.27
29: J81.29
30: J81.30
43: J81.43
53: J81.53
54: J81.54
63: J81.63
64: J81.64
73: J81.73
74: J81.74
83: J81.83
90: J81.90
FPGA_3V3: J81.2, J81.4, J81.8, J81.9, J81.10, J81.11, J81.92; also elsewhere on the board
FPGA_CONFIG_RESET_N: J81.17; also elsewhere on the board
FPGA_LINK_CS_N: J81.23; also elsewhere on the board
FPGA_LINK_DQ0: J81.22; also elsewhere on the board
FPGA_LINK_DQ1: J81.24; also elsewhere on the board
FPGA_LINK_DQ2: J81.26; also elsewhere on the board
FPGA_LINK_DQ3: J81.28; also elsewhere on the board
FPGA_LINK_SCLK: J81.21; also elsewhere on the board
FPGA_RESET_N: J81.13; also elsewhere on the board
FPGA_UART_RX: J81.12; also elsewhere on the board
FPGA_UART_TX: J81.14; also elsewhere on the board
FPGA_VIN: J81.1, J81.3, J81.5, J81.7; also elsewhere on the board
GND: J81.19, J81.39, J81.40, J81.49, J81.50, J81.59, J81.60, J81.69, J81.70, J81.79, J81.80, J81.89, J81.101; also elsewhere on the board
JTAG_TCK: J81.100; also elsewhere on the board
JTAG_TDI: J81.96; also elsewhere on the board
JTAG_TDO: J81.98; also elsewhere on the board
JTAG_TMS: J81.94; also elsewhere on the board
j81-15: J81.15
j81-18: J81.18
j81-20: J81.20
j81-31: J81.31
j81-32: J81.32
j81-33: J81.33
j81-34: J81.34
j81-35: J81.35
j81-36: J81.36
j81-37: J81.37
j81-38: J81.38
j81-41: J81.41
j81-42: J81.42
j81-44: J81.44
j81-45: J81.45
j81-46: J81.46
j81-47: J81.47
j81-48: J81.48
j81-51: J81.51
j81-52: J81.52
j81-55: J81.55
j81-56: J81.56
j81-57: J81.57
j81-58: J81.58
j81-61: J81.61
j81-62: J81.62
j81-65: J81.65
j81-66: J81.66
j81-67: J81.67
j81-68: J81.68
j81-71: J81.71
j81-72: J81.72
j81-75: J81.75
j81-76: J81.76
j81-77: J81.77
j81-78: J81.78
j81-81: J81.81
j81-82: J81.82
j81-84: J81.84
j81-85: J81.85
j81-86: J81.86
j81-87: J81.87
j81-88: J81.88
j81-91: J81.91
j81-93: J81.93
j81-95: J81.95
j81-97: J81.97
j81-99: J81.99

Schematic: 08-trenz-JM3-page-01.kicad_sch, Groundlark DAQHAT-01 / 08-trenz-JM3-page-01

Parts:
J82: LSHM-130-04.0-L-DV-A-S-K-TR; TZ_TZ60; MPN LSHM-130-04.0-L-DV-A-S-K-TR

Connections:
1: J82.1
2: J82.2
4: J82.4
7: J82.7
8: J82.8
10: J82.10
13: J82.13
14: J82.14
19: J82.19
GND: J82.5, J82.6, J82.11, J82.12, J82.17, J82.18, J82.23, J82.24, J82.29, J82.30, J82.35, J82.36, J82.45, J82.46, J82.61; also elsewhere on the board
j82-3: J82.3
j82-9: J82.9
j82-15: J82.15
j82-16: J82.16
j82-20: J82.20
j82-21: J82.21
j82-22: J82.22
j82-25: J82.25
j82-26: J82.26
j82-27: J82.27
j82-28: J82.28
j82-31: J82.31
j82-32: J82.32
j82-33: J82.33
j82-34: J82.34
j82-37: J82.37
j82-38: J82.38
j82-39: J82.39
j82-40: J82.40
j82-41: J82.41
j82-42: J82.42
j82-43: J82.43
j82-44: J82.44
j82-47: J82.47
j82-48: J82.48
j82-49: J82.49
j82-50: J82.50
j82-51: J82.51
j82-52: J82.52
j82-53: J82.53
j82-54: J82.54
j82-55: J82.55
j82-56: J82.56
j82-57: J82.57
j82-58: J82.58
j82-59: J82.59
j82-60: J82.60

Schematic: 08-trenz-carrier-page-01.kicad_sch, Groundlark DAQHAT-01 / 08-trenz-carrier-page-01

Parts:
F80: 0467005.NR; TZ_TZ_FUSE; MPN 0467005.NR
J83: 1715721; TZ_TZ_POWER; MPN 1715721
JP80, JP81: TSW-102-07-G-S; TZ_TZ_JP; MPN TSW-102-07-G-S
R80, R81: 10k; Resistor_SMD__R_0603_1608Metric; MPN RC0603FR-0710KL

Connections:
EXT_3V3: F80.1, J83.1
FPGA_CONFIG_RESET_N: JP81.1; also elsewhere on the board
FPGA_EN1: JP80.1; also elsewhere on the board
FPGA_JTAGEN: R80.1; also elsewhere on the board
FPGA_NOSEQ: R81.1; also elsewhere on the board
FPGA_VIN: F80.2; also elsewhere on the board
GND: J83.2, JP80.2, JP81.2, R80.2, R81.2; also elsewhere on the board

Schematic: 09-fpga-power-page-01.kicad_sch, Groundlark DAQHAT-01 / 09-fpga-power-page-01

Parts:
C80, C81, C82: 22u; Capacitor_SMD__C_1206_3216Metric; MPN GRM31CR61A226KE19L
C83: 100n; Capacitor_SMD__C_0603_1608Metric; MPN GRM188R71H104KA93D
C84, C85: 4.7u; Capacitor_SMD__C_0805_2012Metric; MPN GRM21BR71A475KA73L

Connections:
FPGA_3V3: C84.1, C85.1; also elsewhere on the board
FPGA_VIN: C80.1, C81.1, C82.1, C83.1; also elsewhere on the board
GND: C80.2, C81.2, C82.2, C83.2, C84.2, C85.2; also elsewhere on the board



Board: 6 copper layers, 85.0 x 56.0 mm, 128 parts (35 on the bottom side), 82 nets.

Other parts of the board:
H1, H2, H3, H4: M2.5 NPTH; MountingHole__MountingHole_2.7mm_M2.5
H80, H81, H82, H83: M3 / 8 mm spacer; TZ_TZ_HOLE

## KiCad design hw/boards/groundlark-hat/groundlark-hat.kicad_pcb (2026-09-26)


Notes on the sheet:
Atopile-derived review schematic - prototype, not released. The Pi hosts acquisition and Coldfoot processing; the USB head has a local MCU. Global net labels connect functional sheets.



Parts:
C1: 100n; Capacitor_SMD__C_0603_1608Metric; MPN GRM188R71H104KA93D
C2, C3: 10u; Capacitor_SMD__C_0805_2012Metric; MPN GRM21BR61A106KE19L
J1: Raspberry Pi 40-pin; Connector_PinHeader_2.54mm__PinHeader_2x20_P2.54mm_Vertical; MPN Samtec ESQ-120-23-G-D
JP1: EEPROM write enable; Connector_PinHeader_2.54mm__PinHeader_1x02_P2.54mm_Vertical; MPN EEPROM write enable
R1, R2: 3.9k; Resistor_SMD__R_0603_1608Metric; MPN RC0603FR-073K9L
R3: 1k; Resistor_SMD__R_0603_1608Metric; MPN RC0603FR-071KL
U1: 24LC32A; Package_SO__SOIC-8_3.9x4.9mm_P1.27mm; MPN 24LC32A-I/SN

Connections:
12: J1.12
32: J1.32
35: J1.35
36: J1.36
38: J1.38
40: J1.40
CF_IO_ENABLE: J1.22; also elsewhere on the board
CF_RESET_GPIO: J1.11; also elsewhere on the board
EEP_WP: JP1.1, R3.1, U1.7 (WP)
GND: C1.2, C2.2, C3.2, J1.6, J1.9, J1.14, J1.20, J1.25, J1.30, J1.34, J1.39, JP1.2, U1.1 (A0), U1.2 (A1), U1.3 (A2), U1.4 (VSS); also elsewhere on the board
ID_SCL: J1.28, R2.1, U1.6 (SCL)
ID_SDA: J1.27, R1.1, U1.5 (SDA)
PI_3V3: C1.1, C2.1, J1.1, J1.17, R1.2, R2.2, R3.2, U1.8 (VCC); also elsewhere on the board
PI_5V: C3.1, J1.2, J1.4; also elsewhere on the board
PI_GNSS_PPS: J1.7; also elsewhere on the board
PI_I2C_SCL: J1.5; also elsewhere on the board
PI_I2C_SDA: J1.3; also elsewhere on the board
PI_IMU1_CS: J1.24; also elsewhere on the board
PI_IMU1_INT: J1.13; also elsewhere on the board
PI_IMU2_CS: J1.26; also elsewhere on the board
PI_IMU2_INT: J1.15; also elsewhere on the board
PI_IMU3_CS: J1.29; also elsewhere on the board
PI_IMU3_INT: J1.16; also elsewhere on the board
PI_IMU4_CS: J1.31; also elsewhere on the board
PI_IMU4_INT: J1.18; also elsewhere on the board
PI_SPI_MISO: J1.21; also elsewhere on the board
PI_SPI_MOSI: J1.19; also elsewhere on the board
PI_SPI_SCLK: J1.23; also elsewhere on the board
PI_TILT_CS: J1.33; also elsewhere on the board
PI_UART_RX: J1.10; also elsewhere on the board
PI_UART_TX: J1.8; also elsewhere on the board
SENSOR_OE_N: J1.37; also elsewhere on the board



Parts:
C12, C13, C14, C15, C16, C17: 100n; Capacitor_SMD__C_0402_1005Metric; MPN GRM155R71C104KA88D
R11, R12, R13: 10k; Resistor_SMD__R_0603_1608Metric; MPN RC0603FR-0710KL
U11, U12, U13: LSM6DSOTR; Package_LGA__LGA-14_3x2.5mm_P0.5mm_LayoutBorder3x4y; MPN LSM6DSOTR

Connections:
9: U11.9 (INT2)
10: U11.10 (OCS_AUX)
11: U11.11 (SDO_AUX)
GND: C12.2, C13.2, C14.2, C15.2, C16.2, C17.2, U11.2 (SDx), U11.3 (SCx), U11.6 (GND), U11.7 (GND), U12.2 (SDx), U12.3 (SCx), U12.6 (GND), U12.7 (GND), U13.2 (SDx), U13.3 (SCx), U13.6 (GND), U13.7 (GND); also elsewhere on the board
IMU1_CS: R11.1, U11.12 (CS); also elsewhere on the board
IMU1_INT: U11.4 (INT1); also elsewhere on the board
IMU2_CS: R12.1, U12.12 (CS); also elsewhere on the board
IMU2_INT: U12.4 (INT1); also elsewhere on the board
IMU3_CS: R13.1, U13.12 (CS); also elsewhere on the board
IMU3_INT: U13.4 (INT1); also elsewhere on the board
SENS_3V3: C12.1, C13.1, C14.1, C15.1, C16.1, C17.1, R11.2, R12.2, R13.2, U11.5 (VDDIO), U11.8 (VDD), U12.5 (VDDIO), U12.8 (VDD), U13.5 (VDDIO), U13.8 (VDD); also elsewhere on the board
SPI_MISO: U11.1 (SDO), U12.1 (SDO), U13.1 (SDO); also elsewhere on the board
SPI_MOSI: U11.14 (SDI), U12.14 (SDI), U13.14 (SDI); also elsewhere on the board
SPI_SCLK: U11.13 (SCLK), U12.13 (SCLK), U13.13 (SCLK); also elsewhere on the board
u12-9: U12.9 (INT2)
u12-10: U12.10 (OCS_AUX)
u12-11: U12.11 (SDO_AUX)
u13-9: U13.9 (INT2)
u13-10: U13.10 (OCS_AUX)
u13-11: U13.11 (SDO_AUX)



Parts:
C18, C19: 100n; Capacitor_SMD__C_0402_1005Metric; MPN GRM155R71C104KA88D
R14: 10k; Resistor_SMD__R_0603_1608Metric; MPN RC0603FR-0710KL
U14: LSM6DSOTR; Package_LGA__LGA-14_3x2.5mm_P0.5mm_LayoutBorder3x4y; MPN LSM6DSOTR

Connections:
GND: C18.2, C19.2, U14.2 (SDx), U14.3 (SCx), U14.6 (GND), U14.7 (GND); also elsewhere on the board
IMU4_CS: R14.1, U14.12 (CS); also elsewhere on the board
IMU4_INT: U14.4 (INT1); also elsewhere on the board
SENS_3V3: C18.1, C19.1, R14.2, U14.5 (VDDIO), U14.8 (VDD); also elsewhere on the board
SPI_MISO: U14.1 (SDO); also elsewhere on the board
SPI_MOSI: U14.14 (SDI); also elsewhere on the board
SPI_SCLK: U14.13 (SCLK); also elsewhere on the board
u14-9: U14.9 (INT2)
u14-10: U14.10 (OCS_AUX)
u14-11: U14.11 (SDO_AUX)

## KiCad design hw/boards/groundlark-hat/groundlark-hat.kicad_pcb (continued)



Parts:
C20, C21, C22, C23: 100n; Capacitor_SMD__C_0402_1005Metric; MPN GRM155R71C104KA88D
C24, C26: 100n; Capacitor_SMD__C_0603_1608Metric; MPN GRM188R71H104KA93D
C25: 4.7u; Capacitor_SMD__C_0805_2012Metric; MPN GRM21BR71A475KA73L
J2: Passive GNSS antenna; Connector_Coaxial__U.FL_Hirose_U.FL-R-SMT-1_Vertical; MPN U.FL-R-SMT-1(10)
R20: 10k; Resistor_SMD__R_0603_1608Metric; MPN RC0603FR-0710KL
U20: SCL3300-D01; Groundlark__SCL3300_D01; MPN SCL3300-D01-10
U21: MAX-M10S; RF_GPS__ublox_MAX; MPN MAX-M10S-00B

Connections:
2: U21.2 (TXD_NC)
3: U21.3 (RXD_NC)
6: U21.6 (V_BCKP)
13: U21.13 (LNA_EN)
14: U21.14 (VCC_RF)
15: U21.15 (VIO_SEL_OPEN_3V3)
18: U21.18 (SAFEBOOT_N)
GND: C20.2, C21.2, C22.2, C23.2, C24.2, C25.2, C26.2, J2.2, U20.1 (AVSS), U20.3 (RESERVED_GND), U20.11 (DVSS), U20.12 (EMC_GND), U21.1 (GND), U21.5 (EXTINT), U21.10 (GND), U21.12 (GND); also elsewhere on the board
GNSS_PPS: U21.4 (TIMEPULSE); also elsewhere on the board
GNSS_RF: J2.1, U21.11 (RF_IN)
I2C_SCL: U21.17 (SCL); also elsewhere on the board
I2C_SDA: U21.16 (SDA); also elsewhere on the board
SENS_3V3: C20.1, C22.1, C24.1, C25.1, C26.1, R20.2, U20.4 (VDD), U20.9 (DVIO), U21.7 (VCC_IO), U21.8 (VCC); also elsewhere on the board
SPI_MISO: U20.6 (MISO); also elsewhere on the board
SPI_MOSI: U20.7 (MOSI); also elsewhere on the board
SPI_SCLK: U20.8 (SCK); also elsewhere on the board
TILT_AEXT: C21.1, U20.2 (A_EXTC)
TILT_CS: R20.1, U20.5 (CSB); also elsewhere on the board
TILT_DEXT: C23.1, U20.10 (D_EXTC)
u21-9: U21.9 (RESET_N)


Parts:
J4: Coldfoot test UART/reset; Connector_PinHeader_2.54mm__PinHeader_1x04_P2.54mm_Vertical; MPN Coldfoot UART service ONLY

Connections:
CF_RESET_N: J4.4; also elsewhere on the board
CF_UART_RX: J4.2; also elsewhere on the board
CF_UART_TX: J4.3; also elsewhere on the board
GND: J4.1; also elsewhere on the board



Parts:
C40: 10u; Capacitor_SMD__C_0805_2012Metric; MPN GRM21BR61A106KE19L
C41, C43, C44, C45, C46, C47: 100n; Capacitor_SMD__C_0603_1608Metric; MPN GRM188R71H104KA93D
C42: 22u; Capacitor_SMD__C_1206_3216Metric; MPN GRM31CR61A226KE19L
R50: 10k; Resistor_SMD__R_0603_1608Metric; MPN RC0603FR-0710KL
U40: TLV1117LV33DCYR; Package_TO_SOT_SMD__SOT-223-3_TabPin2; MPN TLV1117LV33DCYR
U41, U42: SN74LVC8T245PWR; Package_SO__TSSOP-24_4.4x7.8mm_P0.65mm; MPN SN74LVC8T245PWR

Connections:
GND: C40.2, C41.2, C42.2, C43.2, C44.2, C45.2, C46.2, C47.2, U40.1 (GND), U41.10 (A8), U41.11 (GND), U41.12 (GND), U41.13 (GND), U42.2 (DIR), U42.11 (GND), U42.12 (GND), U42.13 (GND), U42.14 (B8), U42.15 (B7); also elsewhere on the board
GNSS_PPS: U42.16 (B6); also elsewhere on the board
IMU1_CS: U41.19 (B3); also elsewhere on the board
IMU1_INT: U42.20 (B2); also elsewhere on the board
IMU2_CS: U41.18 (B4); also elsewhere on the board
IMU2_INT: U42.19 (B3); also elsewhere on the board
IMU3_CS: U41.17 (B5); also elsewhere on the board
IMU3_INT: U42.18 (B4); also elsewhere on the board
IMU4_CS: U41.16 (B6); also elsewhere on the board
IMU4_INT: U42.17 (B5); also elsewhere on the board
PI_3V3: C44.1, C46.1, R50.2, U41.1 (VCCA), U41.2 (DIR), U42.1 (VCCA); also elsewhere on the board
PI_5V: C40.1, C41.1, U40.3 (IN); also elsewhere on the board
PI_GNSS_PPS: U42.8 (A6); also elsewhere on the board
PI_IMU1_CS: U41.5 (A3); also elsewhere on the board
PI_IMU1_INT: U42.4 (A2); also elsewhere on the board
PI_IMU2_CS: U41.6 (A4); also elsewhere on the board
PI_IMU2_INT: U42.5 (A3); also elsewhere on the board
PI_IMU3_CS: U41.7 (A5); also elsewhere on the board
PI_IMU3_INT: U42.6 (A4); also elsewhere on the board
PI_IMU4_CS: U41.8 (A6); also elsewhere on the board
PI_IMU4_INT: U42.7 (A5); also elsewhere on the board
PI_SPI_MISO: U42.3 (A1); also elsewhere on the board
PI_SPI_MOSI: U41.3 (A1); also elsewhere on the board
PI_SPI_SCLK: U41.4 (A2); also elsewhere on the board
PI_TILT_CS: U41.9 (A7); also elsewhere on the board
SENSOR_OE_N: R50.1, U41.22 (OE_N), U42.22 (OE_N); also elsewhere on the board
SENS_3V3: C42.1, C43.1, C45.1, C47.1, U40.2 (OUT), U41.23 (VCCB), U41.24 (VCCB), U42.23 (VCCB), U42.24 (VCCB); also elsewhere on the board
SPI_MISO: U42.21 (B1); also elsewhere on the board
SPI_MOSI: U41.21 (B1); also elsewhere on the board
SPI_SCLK: U41.20 (B2); also elsewhere on the board
TILT_CS: U41.15 (B7); also elsewhere on the board
u41-14: U41.14 (B8)
u42-9: U42.9 (A7)
u42-10: U42.10 (A8)



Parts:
C48, C49: 100n; Capacitor_SMD__C_0603_1608Metric; MPN GRM188R71H104KA93D
R51: 100k; Resistor_SMD__R_0603_1608Metric; MPN RC0603FR-07100KL
R52, R53: 4.7k; Resistor_SMD__R_0603_1608Metric; MPN RC0603FR-074K7L
TP1: SENS_3V3; TestPoint__TestPoint_Pad_D1.5mm; MPN SENS_3V3
TP2: GND; TestPoint__TestPoint_Pad_D1.5mm; MPN GND
TP4: SENSOR_OE_N; TestPoint__TestPoint_Pad_D1.5mm; MPN SENSOR_OE_N
U43: ISO1640BDR; Package_SO__SOIC-8_3.9x4.9mm_P1.27mm; MPN ISO1640BDR

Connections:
GND: C48.2, C49.2, R51.2, TP2.1, U43.4 (GND1), U43.5 (GND2); also elsewhere on the board
I2C_SCL: R53.1, U43.6 (SCL2); also elsewhere on the board
I2C_SDA: R52.1, U43.7 (SDA2); also elsewhere on the board
PI_3V3: C48.1, U43.1 (VCC1); also elsewhere on the board
PI_I2C_SCL: U43.3 (SCL1); also elsewhere on the board
PI_I2C_SDA: U43.2 (SDA1); also elsewhere on the board
SENSOR_OE_N: TP4.1; also elsewhere on the board
SENS_3V3: C49.1, R52.2, R53.2, TP1.1, U43.8 (VCC2); also elsewhere on the board
SPI_MISO: R51.1; also elsewhere on the board

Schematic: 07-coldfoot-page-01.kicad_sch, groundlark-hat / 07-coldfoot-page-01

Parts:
C60, C61: 10u; Capacitor_SMD__C_0805_2012Metric; MPN GRM21BR61A106KE19L
C62, C67: 100n; Capacitor_SMD__C_0603_1608Metric; MPN GRM188R71H104KA93D
C63, C64, C65, C66: 22u; Capacitor_SMD__C_1206_3216Metric; MPN GRM31CR61A226KE19L
J5: Coldfoot run-1 1x1; Coldfoot_Run1_70DS; MPN HC-PBB40C-70DS-0.4V-3.0-02
L1: 4.7uH; Inductor_SMD__L_Bourns_SRN6045TA; MPN SRN6045TA-4R7M
R60: 0.1; Resistor_SMD__R_1206_3216Metric; MPN ERJ-8CWFR100V
U50: AP63203WU-7; Package_TO_SOT_SMD__TSOT-23-6; MPN AP63203WU-7

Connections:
28: J5.28 (analog[1].pad)
29: J5.29 (analog[0].pad)
CF_3V3: C66.1, C67.1, J5.9 (dvdd_pads[5].pad), J5.11 (vdd_pads[1].pad), J5.19 (dvdd_pads[4].pad), J5.24 (dvdd_pads[3].pad), J5.44 (dvdd_pads[2].pad), J5.46 (vdd_pads[0].pad), J5.54 (dvdd_pads[1].pad), J5.62 (dvdd_pads[0].pad), R60.2; also elsewhere on the board
CF_BIDIR_2: J5.4 (bidir[2].pad); also elsewhere on the board
CF_BIDIR_3: J5.3 (bidir[3].pad); also elsewhere on the board
CF_BIDIR_4: J5.2 (bidir[4].pad); also elsewhere on the board
CF_BIDIR_5: J5.1 (bidir[5].pad); also elsewhere on the board
CF_BIDIR_6: J5.70 (bidir[6].pad); also elsewhere on the board
CF_BIDIR_7: J5.69 (bidir[7].pad); also elsewhere on the board
CF_BIDIR_8: J5.68 (bidir[8].pad); also elsewhere on the board
CF_BIDIR_9: J5.67 (bidir[9].pad); also elsewhere on the board
CF_BIDIR_10: J5.66 (bidir[10].pad); also elsewhere on the board
CF_BIDIR_11: J5.65 (bidir[11].pad); also elsewhere on the board
CF_BIDIR_12: J5.64 (bidir[12].pad); also elsewhere on the board
CF_BIDIR_13: J5.63 (bidir[13].pad); also elsewhere on the board
CF_BIDIR_14: J5.60 (bidir[14].pad); also elsewhere on the board
CF_BIDIR_15: J5.59 (bidir[15].pad); also elsewhere on the board
CF_BIDIR_16: J5.58 (bidir[16].pad); also elsewhere on the board
CF_BIDIR_17: J5.57 (bidir[17].pad); also elsewhere on the board
CF_BIDIR_18: J5.56 (bidir[18].pad); also elsewhere on the board
CF_BIDIR_19: J5.55 (bidir[19].pad); also elsewhere on the board
CF_BIDIR_20: J5.52 (bidir[20].pad); also elsewhere on the board
CF_BIDIR_21: J5.51 (bidir[21].pad); also elsewhere on the board
CF_BIDIR_22: J5.50 (bidir[22].pad); also elsewhere on the board
CF_BIDIR_23: J5.49 (bidir[23].pad); also elsewhere on the board
CF_BIDIR_24: J5.48 (bidir[24].pad); also elsewhere on the board
CF_BIDIR_25: J5.47 (bidir[25].pad); also elsewhere on the board
CF_BIDIR_26: J5.43 (bidir[26].pad); also elsewhere on the board
CF_BIDIR_27: J5.42 (bidir[27].pad); also elsewhere on the board
CF_BIDIR_28: J5.41 (bidir[28].pad); also elsewhere on the board
CF_BIDIR_29: J5.40 (bidir[29].pad); also elsewhere on the board
CF_BIDIR_30: J5.39 (bidir[30].pad); also elsewhere on the board
CF_BIDIR_31: J5.38 (bidir[31].pad); also elsewhere on the board
CF_BIDIR_32: J5.37 (bidir[32].pad); also elsewhere on the board
CF_BIDIR_33: J5.36 (bidir[33].pad); also elsewhere on the board
CF_BIDIR_34: J5.35 (bidir[34].pad); also elsewhere on the board
CF_BIDIR_35: J5.34 (bidir[35].pad); also elsewhere on the board
CF_BIDIR_36: J5.33 (bidir[36].pad); also elsewhere on the board
CF_BIDIR_37: J5.32 (bidir[37].pad); also elsewhere on the board
CF_BIDIR_38: J5.31 (bidir[38].pad); also elsewhere on the board
CF_BIDIR_39: J5.30 (bidir[39].pad); also elsewhere on the board
CF_BST: C62.1, U50.6 (BST)
CF_IN_1: J5.26 (inputs[1].pad); also elsewhere on the board
CF_IN_2: J5.23 (inputs[2].pad); also elsewhere on the board
CF_IN_4: J5.21 (inputs[4].pad); also elsewhere on the board
CF_IN_5: J5.20 (inputs[5].pad); also elsewhere on the board
CF_IN_6: J5.17 (inputs[6].pad); also elsewhere on the board
CF_IN_7: J5.16 (inputs[7].pad); also elsewhere on the board
CF_IN_8: J5.15 (inputs[8].pad); also elsewhere on the board
CF_IN_9: J5.14 (inputs[9].pad); also elsewhere on the board
CF_IN_10: J5.13 (inputs[10].pad); also elsewhere on the board
CF_IN_11: J5.12 (inputs[11].pad); also elsewhere on the board
CF_MESH_CLK: J5.8 (clk_pad); also elsewhere on the board
CF_REG_3V3: C63.1, C64.1, C65.1, L1.2, R60.1, U50.1 (FB)
CF_RESET_N: J5.7 (rst_n_pad); also elsewhere on the board
CF_SW: C62.2, L1.1, U50.5 (SW)
CF_TELEMETRY: J5.5 (bidir[1].pad)
CF_TILE_CLK: J5.22 (inputs[3].pad); also elsewhere on the board
CF_UART_RX: J5.27 (inputs[0].pad); also elsewhere on the board
CF_UART_TX: J5.6 (bidir[0].pad); also elsewhere on the board
GND: C60.2, C61.2, C63.2, C64.2, C65.2, C66.2, C67.2, J5.10 (dvss_pads[0].pad), J5.18 (dvss_pads[0].pad), J5.25 (dvss_pads[0].pad), J5.45 (dvss_pads[0].pad), J5.53 (dvss_pads[0].pad), J5.61 (dvss_pads[0].pad), U50.4 (GND); also elsewhere on the board
PI_5V: C60.1, C61.1, U50.2 (EN), U50.3 (VIN); also elsewhere on the board

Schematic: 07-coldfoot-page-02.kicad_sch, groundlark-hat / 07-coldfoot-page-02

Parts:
C68, C69, C70, C71, C72, C73, C74, C75, C76: 100n; Capacitor_SMD__C_0603_1608Metric; MPN GRM188R71H104KA93D
R61: 47; Resistor_SMD__R_0603_1608Metric; MPN RC0603FR-0747RL
R62: 100k; Resistor_SMD__R_0603_1608Metric; MPN RC0603FR-07100KL
U51: TXU0202DCUR; Package_SO__VSSOP-8_2.3x2mm_P0.5mm; MPN TXU0202DCUR

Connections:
CF_3V3: C68.1, C69.1, C70.1, C71.1, C72.1, C73.1, C74.1, C76.1, U51.7 (VCCB); also elsewhere on the board
CF_IO_ENABLE: R62.1, U51.6 (OE); also elsewhere on the board
CF_UART_DRIVE: R61.1, U51.8 (B1Y_OUT)
CF_UART_RX: R61.2; also elsewhere on the board
CF_UART_TX: U51.1 (B2_IN); also elsewhere on the board
GND: C68.2, C69.2, C70.2, C71.2, C72.2, C73.2, C74.2, C75.2, C76.2, R62.2, U51.2 (GND); also elsewhere on the board
PI_3V3: C75.1, U51.3 (VCCA); also elsewhere on the board
PI_UART_RX: U51.4 (A2Y_OUT); also elsewhere on the board
PI_UART_TX: U51.5 (A1_IN); also elsewhere on the board

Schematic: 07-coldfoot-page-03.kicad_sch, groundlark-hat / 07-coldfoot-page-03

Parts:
C77, C78: 100n; Capacitor_SMD__C_0603_1608Metric; MPN GRM188R71H104KA93D
Q1: 2N7002; Package_TO_SOT_SMD__SOT-23; MPN 2N7002
R63, R64: 10k; Resistor_SMD__R_0603_1608Metric; MPN RC0603FR-0710KL
R65: 1k; Resistor_SMD__R_0603_1608Metric; MPN RC0603FR-071KL
R66: 100k; Resistor_SMD__R_0603_1608Metric; MPN RC0603FR-07100KL
R67, R68: 33; Resistor_SMD__R_0603_1608Metric; MPN RC0603FR-0733RL
U52: TLV803EA30DBZR; Package_TO_SOT_SMD__SOT-23; MPN TLV803EA30DBZR
Y1, Y2: 25MHz; Crystal__Crystal_SMD_3225-4Pin_3.2x2.5mm; MPN ASE-25.000MHZ-L-C-T

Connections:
CF_3V3: C77.1, C78.1, R63.2, R64.2, U52.3 (VDD), Y1.1 (ENABLE), Y1.4 (VDD), Y2.1 (ENABLE), Y2.4 (VDD); also elsewhere on the board
CF_MESH_CLK: R67.2; also elsewhere on the board
CF_MESH_CLK_RAW: R67.1, Y1.3 (OUT)
CF_RESET_GATE: Q1.1 (G), R65.2, R66.1
CF_RESET_GPIO: R65.1; also elsewhere on the board
CF_RESET_N: Q1.3 (D), R64.1, U52.2 (RESET_N); also elsewhere on the board
CF_TILE_CLK: R68.2; also elsewhere on the board
CF_TILE_CLK_RAW: R68.1, Y2.3 (OUT)
CF_UART_RX: R63.1; also elsewhere on the board
GND: C77.2, C78.2, Q1.2 (S), R66.2, U52.1 (GND), Y1.2 (GND), Y2.2 (GND); also elsewhere on the board

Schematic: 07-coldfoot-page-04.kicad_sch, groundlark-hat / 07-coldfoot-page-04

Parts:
C79: 100n; Capacitor_SMD__C_0603_1608Metric; MPN GRM188R71H104KA93D
R100, R101, R102, R103, R104, R105, R106, R107, R108, R109, R110: 100k; Resistor_SMD__R_0603_1608Metric; MPN RC0603FR-07100KL

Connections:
CF_3V3: C79.1; also elsewhere on the board
CF_BIDIR_2: R110.1; also elsewhere on the board
CF_IN_1: R100.1; also elsewhere on the board
CF_IN_2: R101.1; also elsewhere on the board
CF_IN_4: R102.1; also elsewhere on the board
CF_IN_5: R103.1; also elsewhere on the board
CF_IN_6: R104.1; also elsewhere on the board
CF_IN_7: R105.1; also elsewhere on the board
CF_IN_8: R106.1; also elsewhere on the board
CF_IN_9: R107.1; also elsewhere on the board
CF_IN_10: R108.1; also elsewhere on the board
CF_IN_11: R109.1; also elsewhere on the board
GND: C79.2, R100.2, R101.2, R102.2, R103.2, R104.2, R105.2, R106.2, R107.2, R108.2, R109.2, R110.2; also elsewhere on the board

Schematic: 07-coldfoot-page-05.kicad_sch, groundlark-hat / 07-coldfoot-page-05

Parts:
R111, R112, R113, R114, R115, R116, R117, R118, R119, R120, R121, R122: 100k; Resistor_SMD__R_0603_1608Metric; MPN RC0603FR-07100KL

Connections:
CF_3V3: R111.2, R122.2; also elsewhere on the board
CF_BIDIR_3: R111.1; also elsewhere on the board
CF_BIDIR_4: R112.1; also elsewhere on the board
CF_BIDIR_5: R113.1; also elsewhere on the board
CF_BIDIR_6: R114.1; also elsewhere on the board
CF_BIDIR_7: R115.1; also elsewhere on the board
CF_BIDIR_8: R116.1; also elsewhere on the board
CF_BIDIR_9: R117.1; also elsewhere on the board
CF_BIDIR_10: R118.1; also elsewhere on the board
CF_BIDIR_11: R119.1; also elsewhere on the board
CF_BIDIR_12: R120.1; also elsewhere on the board
CF_BIDIR_13: R121.1; also elsewhere on the board
CF_BIDIR_14: R122.1; also elsewhere on the board
GND: R112.2, R113.2, R114.2, R115.2, R116.2, R117.2, R118.2, R119.2, R120.2, R121.2; also elsewhere on the board

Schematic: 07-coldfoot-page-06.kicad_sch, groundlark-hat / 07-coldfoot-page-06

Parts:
R123, R124, R125, R126, R127, R128, R129, R130, R131, R132, R133, R134: 100k; Resistor_SMD__R_0603_1608Metric; MPN RC0603FR-07100KL

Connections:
CF_BIDIR_15: R123.1; also elsewhere on the board
CF_BIDIR_16: R124.1; also elsewhere on the board
CF_BIDIR_17: R125.1; also elsewhere on the board
CF_BIDIR_18: R126.1; also elsewhere on the board
CF_BIDIR_19: R127.1; also elsewhere on the board
CF_BIDIR_20: R128.1; also elsewhere on the board
CF_BIDIR_21: R129.1; also elsewhere on the board
CF_BIDIR_22: R130.1; also elsewhere on the board
CF_BIDIR_23: R131.1; also elsewhere on the board
CF_BIDIR_24: R132.1; also elsewhere on the board
CF_BIDIR_25: R133.1; also elsewhere on the board
CF_BIDIR_26: R134.1; also elsewhere on the board
GND: R123.2, R124.2, R125.2, R126.2, R127.2, R128.2, R129.2, R130.2, R131.2, R132.2, R133.2, R134.2; also elsewhere on the board

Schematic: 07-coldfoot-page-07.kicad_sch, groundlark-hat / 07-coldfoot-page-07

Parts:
R135, R136, R137, R138, R139, R140, R141, R142, R143, R144, R145, R146: 100k; Resistor_SMD__R_0603_1608Metric; MPN RC0603FR-07100KL

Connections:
CF_3V3: R135.2, R141.2; also elsewhere on the board
CF_BIDIR_27: R135.1; also elsewhere on the board
CF_BIDIR_28: R136.1; also elsewhere on the board
CF_BIDIR_29: R137.1; also elsewhere on the board
CF_BIDIR_30: R138.1; also elsewhere on the board
CF_BIDIR_31: R139.1; also elsewhere on the board
CF_BIDIR_32: R140.1; also elsewhere on the board
CF_BIDIR_33: R141.1; also elsewhere on the board
CF_BIDIR_34: R142.1; also elsewhere on the board
CF_BIDIR_35: R143.1; also elsewhere on the board
CF_BIDIR_36: R144.1; also elsewhere on the board
CF_BIDIR_37: R145.1; also elsewhere on the board
CF_BIDIR_38: R146.1; also elsewhere on the board
GND: R136.2, R137.2, R138.2, R139.2, R140.2, R142.2, R143.2, R144.2, R145.2, R146.2; also elsewhere on the board

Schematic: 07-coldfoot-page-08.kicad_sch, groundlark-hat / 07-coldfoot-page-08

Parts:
R147: 100k; Resistor_SMD__R_0603_1608Metric; MPN RC0603FR-07100KL

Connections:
CF_BIDIR_39: R147.1; also elsewhere on the board
GND: R147.2; also elsewhere on the board


Board: 6 copper layers, 120.0 x 56.0 mm, 147 parts (0 on the bottom side), 106 nets.

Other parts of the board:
H1, H2, H3, H4: M2.5 NPTH; MountingHole__MountingHole_2.7mm_M2.5

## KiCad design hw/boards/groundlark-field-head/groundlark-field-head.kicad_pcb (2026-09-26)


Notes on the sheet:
Atopile-derived review schematic - prototype, not released. The Pi hosts acquisition and Coldfoot processing; the USB head has a local MCU. Global net labels connect functional sheets.

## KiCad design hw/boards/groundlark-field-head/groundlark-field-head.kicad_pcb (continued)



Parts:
C1: 2.2u; Capacitor_SMD__C_0805_2012Metric; MPN GRM21BR71E225KA73L
C2: 4.7u; Capacitor_SMD__C_0805_2012Metric; MPN GRM21BR71A475KA73L
D1, D2: USBLC6-2SC6; Package_TO_SOT_SMD__SOT-23-6; MPN USBLC6-2SC6
F1: 500mA PTC; Fuse__Fuse_1812_4532Metric; MPN MF-MSMF050-2
J1: USB-C DEVICE; Connector_USB__USB_C_Receptacle_GCT_USB4105-xx-A_16P_TopMnt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; MPN USB4105-GF-A
R1, R2: 5.1k; Resistor_SMD__R_0603_1608Metric; MPN RC0603FR-075K1L
U4: AP2112K-3.3; Package_TO_SOT_SMD__SOT-23-5; MPN AP2112K-3.3TRG1

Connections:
4: U4.4 (NC)
A8: J1.A8
B8: J1.B8
GND: C1.2, C2.2, D1.2, D2.2, J1.A1, J1.A12, J1.B1, J1.B12, J1.S1, R1.2, R2.2, U4.2 (GND); also elsewhere on the board
USB_5V: C1.1, F1.2, U4.1 (VIN), U4.3 (EN)
USB_CC1: D2.1, D2.6, J1.A5, R1.1
USB_CC2: D2.3, D2.4, J1.B5, R2.1
USB_DM: D1.3, D1.4, J1.A7, J1.B7; also elsewhere on the board
USB_DP: D1.1, D1.6, J1.A6, J1.B6; also elsewhere on the board
USB_VBUS: D1.5, D2.5, F1.1, J1.A4, J1.A9, J1.B4, J1.B9
V3: C2.1, U4.5 (VOUT); also elsewhere on the board



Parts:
C3, C6, C7, C8: 100n; Capacitor_SMD__C_0603_1608Metric; MPN GRM188R71H104KA93D
J2: SWD / 3V3 SENSE; Connector_PinHeader_2.54mm__PinHeader_1x05_P2.54mm_Vertical; MPN M20-9990545
J3: BOOT0 jumper; Connector_PinHeader_2.54mm__PinHeader_1x02_P2.54mm_Vertical; MPN EEPROM write enable
R3, R4: 10k; Resistor_SMD__R_0603_1608Metric; MPN RC0603FR-0710KL
U1: STM32F042K6T6; Package_QFP__LQFP-32_7x7mm_P0.8mm; MPN STM32F042K6T6

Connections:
2: U1.2 (PF0)
3: U1.3 (PF1)
7: U1.7 (PA1)
8: U1.8 (PA2)
9: U1.9 (PA3)
10: U1.10 (PA4)
11: U1.11 (PA5)
12: U1.12 (PA6)
13: U1.13 (PA7)
15: U1.15 (PB1)
18: U1.18 (PA8)
19: U1.19 (PA9)
20: U1.20 (PA10)
25: U1.25 (PA15)
26: U1.26 (PB3)
27: U1.27 (PB4)
28: U1.28 (PB5)
BOOT0: J3.2, R4.1, U1.31 (BOOT0)
GND: C3.2, C6.2, C7.2, C8.2, J2.3, R4.2, U1.16 (VSS), U1.32 (VSS); also elsewhere on the board
MAG_DRDY: U1.14 (PB0); also elsewhere on the board
NRST: C8.1, J2.5, R3.2, U1.4 (NRST)
SCL: U1.29 (I2C_SCL); also elsewhere on the board
SDA: U1.30 (I2C_SDA); also elsewhere on the board
SENSOR_EN: U1.6 (PA0); also elsewhere on the board
SWCLK: J2.4, U1.24 (SWCLK)
SWDIO: J2.2, U1.23 (SWDIO)
USB_DM: U1.21 (USB_DM); also elsewhere on the board
USB_DP: U1.22 (USB_DP); also elsewhere on the board
V3: C3.1, C6.1, C7.1, J2.1, J3.1, R3.1, U1.1 (VDD), U1.5 (VDDA), U1.17 (VDDIO2); also elsewhere on the board

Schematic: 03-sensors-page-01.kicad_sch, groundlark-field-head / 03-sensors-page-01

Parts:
C4, C5, C9: 100n; Capacitor_SMD__C_0603_1608Metric; MPN GRM188R71H104KA93D
R5: 100k; Resistor_SMD__R_0603_1608Metric; MPN RC0603FR-07100KL
R7, R8: 4.7k; Resistor_SMD__R_0603_1608Metric; MPN RC0603FR-074K7L
U2: RM3100 XYZ; Groundlark__PNI_14190_Module; MPN PNI 14190
U3: DLVR-F50D option; Groundlark__DLVR_E1BS; MPN DLVR-F50D-E1BS-I-NI3F; not fitted
U5: TPS22919; Package_TO_SOT_SMD__SOT-363_SC-70-6; MPN TPS22919DCKR

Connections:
6: U2.6 (NC)
GND: C4.2, C5.2, C9.2, R5.2, U2.2 (SA1), U2.4 (SA0), U2.7 (AVSS), U2.14 (DVSS), U3.1 (GND), U5.2 (GND); also elsewhere on the board
MAG_DRDY: U2.5 (DRDY); also elsewhere on the board
SCL: R8.1, U2.1 (SCL), U3.4 (SCL); also elsewhere on the board
SDA: R7.1, U2.3 (SDA), U3.3 (SDA); also elsewhere on the board
SENSOR_EN: R5.1, U5.3 (ON); also elsewhere on the board
V3: C9.1, U5.1 (IN); also elsewhere on the board
V3_SENSOR: C4.1, C5.1, R7.2, R8.2, U2.10 (I2CEN), U2.12 (DVDD), U2.13 (AVDD), U3.2 (VS_3V3), U5.5 (QOD), U5.6 (OUT)
u2-8: U2.8 (NC)
u2-9: U2.9 (NC)
u2-11: U2.11 (NC)
u5-4: U5.4 (NC)


Board: 4 copper layers, 70.0 x 45.0 mm, 31 parts (0 on the bottom side), 17 nets.

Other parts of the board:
H1, H2, H3, H4: M2.5 NPTH; MountingHole__MountingHole_2.7mm_M2.5

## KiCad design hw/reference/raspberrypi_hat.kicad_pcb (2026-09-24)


Board: 4 copper layers, 65.0 x 56.0 mm, 18 parts (1 on the bottom side), 10 nets.

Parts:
H1, H2, H3, H4: 3mm_Mounting_Hole; NPTH_3mm_ID
J3: 40HAT; PinSocket_2x20_P2.54mm_Vertical
J6: CONN_02X02; PinHeader_2x02_P2.54mm_Vertical
J9: CONN_01X02; PinHeader_1x02_P2.54mm_Vertical
Q1: DMG2305UX; SOT-23
Q2: DMMT5401; SOT-23-6
R6, R8: 3.9K; R_0603_1608Metric_Pad0.84x1.00mm_HandSolder
R7, R9, R11: DNP; R_0603_1608Metric_Pad0.84x1.00mm_HandSolder
R23, R29: 10K; R_0603_1608Metric_Pad0.84x1.00mm_HandSolder
R24: 47K; R_0603_1608Metric_Pad0.84x1.00mm_HandSolder
U2: CAT24C32; SOIC-8_3.9x4.9mm_P1.27mm

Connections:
/ID_SC_EEPROM: J3.28, R8.2, U2.6
/ID_SD_EEPROM: J3.27, R6.2, U2.5
/P3V3: J6.1, R6.1, R7.2, R8.1, R29.1, U2.8
/P3V3_HAT: J3.1, J6.2, R7.1
/P5V: J6.3, Q1.3, Q2.6, R9.2
/P5V_HAT: J3.2, J3.4, J6.4, Q1.2, Q2.5, R9.1
GND: J3.6, J3.9, J3.14, J3.20, J3.25, J3.30, J3.34, J3.39, J9.1, R11.2, R23.2, R24.2, U2.1, U2.2, U2.3, U2.4
unnamed: J9.2, R11.1, R29.2, U2.7
unnamed: Q1.1, Q2.4, R24.1
unnamed: Q2.1, Q2.2, Q2.3, R23.1

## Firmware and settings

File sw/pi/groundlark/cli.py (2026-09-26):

"""The same acquisition, validation and recording path for sim and Linux."""
import argparse
from collections import Counter
import hashlib
import json
import os
from pathlib import Path
import secrets
import sys
import time
from .calibration import Calibrations, canonical
from .messages import configuration
from .recording import Reader, Writer, is_acquisition_metadata
from .runtime import Acquisition, Channel
from .session import Sessions
from .simulation import Simulated, defaults
from .stimulus import Scenario


def load_json(path, limit=16384):
    with open(path, "rb") as stream: data = stream.read(limit + 1)
    if len(data) > limit: raise ValueError("JSON input byte limit")
    return json.loads(data, parse_constant=lambda value: (_ for _ in ()).throw(ValueError(value)))


def replay(path):
    counts, digest = Counter(), hashlib.sha256()
    completed = False
    with open(path, "rb") as stream:
        reader = Reader(stream)
        if not is_acquisition_metadata(reader.metadata):
            raise ValueError("recording application metadata")
        calibrations = Calibrations(reader.metadata.get("calibrations", []))
        sessions = Sessions(calibrations)
        for arrived, item in reader:
            completed = isinstance(item, dict) and item.get("code") == "acquisition_summary"
            if isinstance(item, dict):
                counts["events"] += 1
                if item.get("code") == "usb_disconnected" and item.get("device") is not None:
                    sessions.disconnect(item["device"])
            else:
                kind = sessions.accept(item)
                counts[kind] += 1
                digest.update(item.SerializeToString(deterministic=True))
                if kind == "batch":
                    for sample in item.batch.samples:
                        counts["samples"] += 1
                        counts[{1: "valid", 2: "missing", 3: "saturated", 4: "fault"}[sample.quality]] += 1
    return dict(counts, completed=completed, message_sha256=digest.hexdigest())


def export_scenario(recording, output):
    """Recover scheduled and interactive changes from a validated recording."""
    replay(recording)
    with open(recording, "rb") as stream:
        reader = Reader(stream)
        if reader.metadata.get("stimulus_model") != "ideal-v1": raise ValueError("recording has no supported stimulus model")
        document = Scenario(reader.metadata["scenario"]).export()
        pending, applied = document["events"][:], []
        for arrived, item in reader:
            if not isinstance(item, dict) or item.get("code") != "stimulus_change": continue
            event = {"at_ns": item["at_ns"], "set": item["set"]}
            if type(event["at_ns"]) is not int or not 0 <= event["at_ns"] <= arrived:
                raise ValueError("invalid recorded control time")
            if event in pending: pending.remove(event)
            applied.append(event)
            if len(applied) > 256: raise ValueError("recorded control limit")
        document["events"] = sorted(applied + pending, key=lambda e: e["at_ns"])
        document = Scenario(document).export()
    with open(output, "x", encoding="utf-8") as stream:
        stream.write(json.dumps(document, indent=2, allow_nan=False) + "\n")
    return dict(scenario=str(output), events=len(document["events"]), seed=reader.metadata["seed"], remote=reader.metadata["remote"])


def run(args):
    simulated = args.command == "simulate"
    utc = getattr(args, 'utc', False)
    if utc: raise ValueError("Current DAQHAT-01 has no GNSS/PPS; use legacy recordings for UTC correlation")
    if utc and not args.fifo: raise ValueError('--utc requires --fifo and PPS profile')
    faults = load_json(args.faults) if getattr(args, "faults", None) else []
    records = load_json(args.calibrations) if args.calibrations else []
    calibrations = Calibrations(records)
    ids = {}
    for ident, record in calibrations.records.items():
        if record["sensor_id"] in ids: raise ValueError("one active calibration per sensor")
        ids[record["sensor_id"]] = ident
    if not 0 < args.seconds <= 3600 or not 1 <= args.drain_every <= 10000: raise ValueError("run bounds")
    settings = defaults()
    channels, enable, usb, pps = [], None, None, None
    if simulated:
        # Human-readable JSON may exceed its bounded canonical representation.
        scenario = Scenario(load_json(args.scenario, 65536) if args.scenario else None)
        current = 0
        clock = lambda: current
        for cfg in settings:
            channels.append(Channel("sim-pi", 1, cfg, Simulated(cfg["sensor_id"], args.seed, faults, scenario, clock)))
        if args.remote:
            for cfg in defaults(True):
                channels.append(Channel("sim-head", 2, cfg, Simulated(cfg["sensor_id"], args.seed, faults, scenario, clock)))
    else:
        if not sys.platform.startswith("linux"): raise ValueError("live acquisition requires Linux")
        from .live import Factory, USB
        from .linux_io import SensorEnable, RisingEdges
        from .worker import Worker
        from .transport import Receiver
        profile = load_json(args.profile)
        if set(profile) - {"device_id", "spi", "i2c", "sensor_enable", "imu_irq", "pps"} or len(profile["spi"]) != 3:
            raise ValueError("live profile requires three explicit SPI paths and sensor OE")
        if len(set(profile["spi"])) != 3: raise ValueError("each sensor needs a separate chip select")
        boot = secrets.randbits(64) or 1
        # Validate all identity/configuration fields before opening devices.
        configuration(profile["device_id"], boot, settings)
        for cfg in settings:
            sid = cfg["sensor_id"]
            path = profile["spi"][(1, 2, 3).index(sid)] if sid in (1, 2, 3) else profile["i2c"]
            channels.append(Channel(profile["device_id"], boot, cfg, Worker(Factory(sid, path, args.fifo and sid in (1, 2, 3), utc and sid == 6), cfg)))
        clock = lambda: time.clock_gettime_ns(time.CLOCK_MONOTONIC_RAW)
    sessions = Sessions(calibrations)
    metadata = dict(format="groundlark-acquisition-v1", source="simulation" if simulated else "linux-polling",
                    calibrations=list(calibrations.records.values()), timing="poll completion; uncertainty unknown")
    if simulated: metadata.update(seed=args.seed, faults=faults, remote=args.remote, stimulus_model="ideal-v1", scenario=scenario.export())
    else:
        metadata["profile"] = profile
        if utc: metadata['utc_capture'] = 'm10-tim-tp-v1'
        if args.fifo:
            metadata.update(source='linux-fifo', timing='IMU device timestamp mapped to RAW; absolute uncertainty unknown; geophone poll completion')
    try:
        # Exclusive create prevents accidentally replacing a prior recording.
        with open(args.output, "xb") as stream:
            writer = Writer(stream, metadata, max_bytes=args.max_mib * 1024 * 1024)
            app = Acquisition(writer, sessions, channels, args.queue, ids)
            if not simulated:
                enable = SensorEnable(**profile["sensor_enable"])
                if profile.get("pps"): raise ValueError("BCM4 is now geophone DRDY, not PPS; update live profile")
                if utc and not profile.get('pps'): raise ValueError('--utc requires PPS line')
                if args.fifo:
                    irqs = profile.get('imu_irq')
                    if irqs is None or len(irqs) != 3: raise ValueError('FIFO profile needs three IMU IRQ lines')
                    pins = [(x['chip'], x['line']) for x in irqs] + [(profile['sensor_enable']['chip'], profile['sensor_enable']['line'])]
                    if profile.get('pps'): pins.append((profile['pps']['chip'], profile['pps']['line']))
                    if len(set(pins)) != len(pins): raise ValueError('duplicate GPIO role')
                    for channel, mapping in zip(channels[:3], irqs): channel.adapter.irq = RisingEdges(**mapping)
                    if profile.get('pps'): pps = RisingEdges(**profile['pps'])
                enable.enabled(True)
                if args.usb:
                    # Independent USB session state prevents peers replacing local identities.
                    usb = USB(args.usb, Receiver(Sessions(calibrations), board=2, forbidden_devices=[profile["device_id"]]))
            start = clock()
            app.start(start)
            end, tick = clock() + int(args.seconds * 1e9), 0
            while clock() < end:
                if simulated:
                    for change in scenario.advance(current):
                        app.event("stimulus_change", "simulation controls changed", current, **change)
                app.tick(clock)
                if pps:
                    raw_before = clock()
                    mono = time.clock_gettime_ns(time.CLOCK_MONOTONIC)
                    raw_after = clock()
                    for edge in pps.read():
                        app.event('pps_edge', 'kernel MONOTONIC edge; UTC association not established', clock(),
                                  monotonic_ns=edge, estimated_raw_ns=edge + (raw_before + raw_after)//2 - mono,
                                  mapping_bracket_ns=raw_after - raw_before, mapping_monotonic_ns=mono)
                if usb:
                    app.drain()
                    usb.poll(clock(), lambda m, t: app.emit(m, t), app.event)
                tick += 1
                if tick % args.drain_every == 0: app.drain()
                if simulated: current += 1_000_000
                else: time.sleep(.001)
            app.finish(clock())
    finally:
        # Close every independent resource even if one worker cannot be reaped.
        errors = []
        for obj in [usb, pps, *[c.adapter for c in channels], enable]:
            if obj is not None:
                try: obj.close()
                except Exception as error: errors.append(error)
        if errors: raise errors[0]
    return replay(args.output)


def main(argv=None):
    parser = argparse.ArgumentParser(description="Groundlark sensor acquisition (no FPGA required)")
    commands = parser.add_subparsers(dest="command", required=True)
    for name in ("simulate", "live"):
        p = commands.add_parser(name)
        p.add_argument("--output", type=Path, required=True)
        p.add_argument("--seconds", type=float, default=2)
        p.add_argument("--queue", type=int, default=64)
        p.add_argument("--drain-every", type=int, default=1)
        p.add_argument("--max-mib", type=int, default=64)
        p.add_argument("--calibrations", type=Path)
        if name == "simulate":
            p.add_argument("--seed", type=int, default=1)
            p.add_argument("--faults", type=Path)
            p.add_argument("--scenario", type=Path, help="versioned SI stimulus scenario JSON")
            p.add_argument("--remote", action="store_true")
        else:
            p.add_argument("--profile", type=Path, required=True)
            p.add_argument("--usb")
            p.add_argument('--fifo', action='store_true', help='buffered IMUs with hardware timestamps and IRQ hints; explicit profile required')
            p.add_argument('--utc', action='store_true', help='legacy option; rejected by current DAQHAT-01 hardware')
    p = commands.add_parser("replay")
    p.add_argument("recording", type=Path)
    p = commands.add_parser("export-scenario", help="recover controls for another deterministic simulation")
    p.add_argument("recording", type=Path)
    p.add_argument("--output", type=Path, required=True)
    args = parser.parse_args(argv)
    try:
        if args.command == "replay": result = replay(args.recording)
        elif args.command == "export-scenario": result = export_scenario(args.recording, args.output)
        else: result = run(args)
    except (ValueError, OSError, KeyError, TypeError) as error:
        parser.exit(1, f"groundlark: {error}\n")
    print(json.dumps(result, sort_keys=True))


if __name__ == "__main__": main()

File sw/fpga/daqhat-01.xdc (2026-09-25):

# Exact TE0712-03-81I36-A schematic, U1 banks 14 and 34.
# R4 CLK50M2 is shifted to 1.5 V on revision 03 (schematic, not generic TRM table).
set_property PACKAGE_PIN R4 [get_ports clk50]
set_property IOSTANDARD LVCMOS15 [get_ports clk50]
create_clock -name fabric -period 20.000 [get_ports clk50]
set_property PACKAGE_PIN W19 [get_ports sclk]
set_property IOSTANDARD LVCMOS33 [get_ports sclk]
set_property PACKAGE_PIN W20 [get_ports cs_n]
set_property IOSTANDARD LVCMOS33 [get_ports cs_n]
set_property PACKAGE_PIN V18 [get_ports dq0]
set_property IOSTANDARD LVCMOS33 [get_ports dq0]
set_property PACKAGE_PIN V19 [get_ports dq1]
set_property IOSTANDARD LVCMOS33 [get_ports dq1]
set_property PACKAGE_PIN AA21 [get_ports uart_rx]
set_property IOSTANDARD LVCMOS33 [get_ports uart_rx]
set_property PACKAGE_PIN AA20 [get_ports uart_tx]
set_property IOSTANDARD LVCMOS33 [get_ports uart_tx]
set_property PACKAGE_PIN AB22 [get_ports reset_n]
set_property IOSTANDARD LVCMOS33 [get_ports reset_n]
set_property DRIVE 4 [get_ports {dq1 uart_tx}]
set_property SLEW SLOW [get_ports {dq1 uart_tx}]
set_property PULLUP true [get_ports {cs_n uart_rx reset_n}]
# Only asynchronous input-to-first-stage paths are excluded. All remaining
# synchronizer stages and mailbox logic are timed at 50 MHz.
set_false_path -from [get_ports sclk] -to [get_pins {ck_reg[0]/D}]
set_false_path -from [get_ports cs_n] -to [get_pins {cs_reg[0]/D}]
set_false_path -from [get_ports dq0] -to [get_pins {di_reg[0]/D}]
set_false_path -from [get_ports reset_n]
# Bound pad propagation, including immediate CS output-disable. These limits
# do not replace measurement of Pi setup/hold or board/switch flight time.
set_max_delay -datapath_only 100 -from [get_clocks fabric] -to [get_ports dq1]
set_max_delay -datapath_only 100 -from [get_ports cs_n] -to [get_ports dq1]
set_max_delay -datapath_only 20 -from [get_ports uart_rx] -to [get_ports uart_tx]
set_property BITSTREAM.CONFIG.UNUSEDPIN PULLNONE [current_design]
set_property CONFIG_VOLTAGE 3.3 [current_design]
set_property CFGBVS VCCO [current_design]

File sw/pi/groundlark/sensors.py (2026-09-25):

"""Small polling drivers with injected buses; manufacturer references in docs."""
from dataclasses import dataclass
from collections import deque
import struct
import time


class NotReady(OSError):
    pass


class DataGap(OSError):
    """Communication succeeded, but conversion continuity was lost.

    Emit a missing marker and unknown loss without resetting a healthy device.
    """


@dataclass
class Reading:
    raw: dict
    quality: int = 1
    acquisition_ns: int | None = None


class LSM6DSO:
    PERIODS = {38461538: 2, 19230769: 3, 9615385: 4, 4807692: 5}

    def __init__(self, bus, sleep=time.sleep, clock=time.monotonic):
        self.bus, self.sleep, self.clock = bus, sleep, clock

    def reg(self, address, count=1):
        data = self.bus.transfer(bytes([address | 0x80]) + bytes(count), mode=0, hz=1_000_000)
        if len(data) != count + 1: raise OSError("short IMU read")
        return data[1:]

    def write(self, address, value):
        self.bus.transfer(bytes([address, value]), mode=0, hz=1_000_000)

    def configure(self, cfg):
        if cfg["period_ns"] not in self.PERIODS: raise ValueError("IMU supports this driver's 26/52/104/208 Hz profiles only")
        if self.reg(0x0f) != b"\x6c": raise OSError("LSM6DSO identity mismatch")
        self.write(0x12, 1)
        for _ in range(100):
            if not self.reg(0x12)[0] & 1: break
            self.sleep(.001)
        else: raise TimeoutError("IMU reset timeout")
        odr = self.PERIODS[cfg["period_ns"]] << 4
        accel = {2: 0, 4: 8, 8: 12, 16: 4}[cfg["acceleration_range_g"]]
        gyro = {125: 2, 250: 0, 500: 4, 1000: 8, 2000: 12}[cfg["angular_rate_range_dps"]]
        settings = {0x10: odr | accel, 0x11: odr | gyro, 0x12: 0x44}
        for address in (0x12, 0x10, 0x11): self.write(address, settings[address])
        for address, value in settings.items():
            if self.reg(address)[0] != value: raise OSError("IMU configuration readback mismatch")
        self.sleep(.1)
        return dict(cfg, register_config=b"".join(bytes([r, v]) for r, v in sorted(settings.items())))

    def read(self):
        if self.reg(0x1e)[0] & 3 != 3: raise NotReady("IMU data not ready")
        values = struct.unpack("<7h", self.reg(0x20, 14))
        return Reading(dict(temperature=values[0], angular_rate=values[1:4], acceleration=values[4:7]),
                       3 if any(v in (-32768, 32767) for v in values[1:]) else 1)


def scl_crc(data):
    crc = 255
    for byte in data:
        crc ^= byte
        for _ in range(8): crc = ((crc << 1) ^ (0x1d if crc & 128 else 0)) & 255
    return crc ^ 255


def scl_command(opcode, value=0):
    data = bytes([opcode]) + value.to_bytes(2, "big")
    return data + bytes([scl_crc(data)])


class SCL3300:
    def __init__(self, bus, sleep=time.sleep):
        self.bus, self.sleep = bus, sleep

    def transfer(self, frame):
        self.sleep(.00002)  # CS high >=10 us; scheduler oversleep is safe.
        data = self.bus.transfer(frame, mode=0, hz=1_000_000)
        if len(data) != 4: raise OSError("short SCL3300 transfer")
        return data

    @staticmethod
    def response(data, opcode):
        if scl_crc(data[:3]) != data[3]: raise OSError("SCL3300 CRC mismatch")
        if data[0] & 0xfc != opcode: raise OSError("SCL3300 off-frame address mismatch")
        return int.from_bytes(data[1:3], "big"), data[0] & 3

    def reg(self, address):
        frame = scl_command(address << 2)
        self.transfer(frame)
        return self.response(self.transfer(frame), address << 2)

    def configure(self, cfg):
        mode = cfg["tilt_mode"]
        if mode not in (1, 2, 3, 4) or cfg["period_ns"] < 10_000_000: raise ValueError("SCL3300 polling profile")
        self.transfer(scl_command(0xb4, 0))
        self.sleep(.003)
        self.transfer(scl_command(0xb4, 0x20))
        self.sleep(.003)
        self.transfer(scl_command(0xb4, mode - 1))
        self.transfer(scl_command(0xb0, 0x1f))
        self.sleep({1: .025, 2: .015, 3: .100, 4: .100}[mode])
        frame = scl_command(0x18)
        self.transfer(frame)
        self.transfer(frame)
        _, rs = self.response(self.transfer(frame), 0x18)
        if rs != 1: raise OSError("SCL3300 startup flags did not clear")
        who, rs = self.reg(0x10)
        actual, mode_rs = self.reg(0x0d)
        if who != 0xc1 or rs != 1 or mode_rs != 1 or actual & 3 != mode - 1:
            raise OSError("SCL3300 identity/mode readback mismatch")
        return cfg

    def read(self):
        values, statuses = [], []
        for address in (1, 2, 3, 9, 10, 11, 5, 6):
            value, rs = self.reg(address)
            values.append(value)
            statuses.append(rs)
        signed = [v - 65536 if v & 32768 else v for v in values[:-1]]
        summary = values[-1]
        quality = 1 if not summary and all(s == 1 for s in statuses) else 4
        if summary == 0x40 and all(s in (1, 3) for s in statuses): quality = 3
        return Reading(dict(acceleration=signed[:3], angle=signed[3:6], temperature=signed[6], device_status=summary), quality)


def ubx_packet(cls, ident, payload):
    data = bytes([cls, ident]) + len(payload).to_bytes(2, "little") + payload
    a = b = 0
    for byte in data:
        a = (a + byte) & 255
        b = (b + a) & 255
    return b"\xb5\x62" + data + bytes([a, b])


class UBXParser:
    def __init__(self):
        self.buffer = bytearray()
        self.errors = 0

    def feed(self, data):
        if len(data) > 256: raise ValueError("UBX input chunk limit")
        self.buffer.extend(data)
        while True:
            start = self.buffer.find(b"\xb5\x62")
            if start < 0:
                self.buffer[:] = self.buffer[-1:] if self.buffer.endswith(b"\xb5") else b""
                return
            del self.buffer[:start]
            if len(self.buffer) < 6: return
            size = int.from_bytes(self.buffer[4:6], "little")
            if size > 1024:
                self.errors += 1
                del self.buffer[0]
                continue
            if len(self.buffer) < size + 8: return
            cls, ident = self.buffer[2:4]
            payload = bytes(self.buffer[6:6 + size])
            if bytes(self.buffer[:size + 8]) != ubx_packet(cls, ident, payload):
                self.errors += 1
                del self.buffer[0]
                continue
            del self.buffer[:size + 8]
            yield cls, ident, payload
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

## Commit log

2026-09-24 Import ShakeSense circuit designs, routed PCBs, documentation, and portable validation lab
    [01-host-power-page-01.kicad_sch, 01-usb-power-page-01.kicad_sch, 02-controller-page-01.kicad_sch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]
2026-09-24 Organize hardware, software, docs, and portable validation tooling
    [01-host-power-page-01.kicad_sch, 01-usb-power-page-01.kicad_sch, 02-controller-page-01.kicad_sch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]
2026-09-24 Expose Trenz GPIOs on the Pi-outline HDI sensor HAT
    [01-host-power-page-01.kicad_sch, 02-motion-array-page-01.kicad_sch, 02-motion-array-page-02.kicad_sch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]
2026-09-24 Add versioned sensor contracts and portable framing validation
2026-09-24 Show non-FPGA board renders on the project homepage
2026-09-24 Implement sensor acquisition simulation replay and bounded recovery
2026-09-24 Add controllable time-based sensor stimulus scenarios
2026-09-24 Add Python sensor workbench with interactive board and replay
2026-09-25 Verify HAT acquisition signals through Pi drivers and UI
2026-09-25 Correct T1 RF and stack clearance; add buffered Pi acquisition and engineering checks
    [assembly-bom.csv, pi-trenz-stack-concept.kicad_pcb, shakesense-trenz-hat.kicad_pcb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]
2026-09-25 Replace T1 GNSS with single Racotech geophone input
    [01-host-power-page-01.kicad_sch, 02-motion-array-page-01.kicad_sch, 02-motion-array-page-02.kicad_sch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]
2026-09-25 Harden geophone acquisition and tighten analog layout
    [03-geophone-page-01.kicad_sch, assembly-bom.csv, bom.csv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]
2026-09-25 Resolve T1 ribbon clearance with guided flex and windowed support
    [T1_offset-spacer.step, T1_ribbon-guide.step, bom.csv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]
2026-09-25 Plan internal QSPI and UART link with switched JTAG and no ribbons
2026-09-25 Implement internal Pi FPGA link and remove ribbon expansion
    [01-host-power-page-01.kicad_sch, 07-internal-link-page-01.kicad_sch, 07-internal-link-page-02.kicad_sch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]
2026-09-25 Harden T1 FPGA transport and expand pre-fab verification
    [shakesense-trenz-hat.kicad_pcb]
2026-09-26 Rename project to Groundlark and sensor carrier to DAQHAT-01
    [01-host-power-page-01.kicad_sch, 01-usb-power-page-01.kicad_sch, 02-controller-page-01.kicad_sch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]
2026-09-26 Harden DAQHAT-01 assembly exports and refresh stack overview
    Publish the current three-IMU six-layer revision and matching software. Capture exact-part sourcing, shortage substitutions and numbered-pad rotation mappings with regression and full/overlay integration tests. Preserve validated BOM bytes across Git checkouts. Replace README images with the current stack and a dimensioned geophone illustration; keep fabrication packages local.
    [01-host-power-page-01.kicad_sch, 02-motion-array-page-01.kicad_sch, 02-motion-array-page-02.kicad_sch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]
2026-09-26 Unify README and simulator branding with Groundlark favicon wordmark
2026-09-26 Focus documentation on setup, hardware and assembly
